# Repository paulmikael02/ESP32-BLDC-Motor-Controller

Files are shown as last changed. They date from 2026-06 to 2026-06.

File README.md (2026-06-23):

# ESP32-Based BLDC Motor Controller (Firmware & Hardware)

***FI** | **[Lue kattava suomenkielinen dokumentaatio tästä](README_FI.md)***

This repository contains the hardware designs (KiCad) and embedded software (ESP-IDF) for a 3-phase brushless DC (BLDC) motor controller.

The project was developed as part of modernizing the educational equipment in the embedded systems laboratory at SeAMK. The old 8-bit ATmega architecture was upgraded to a modern 32-bit ESP32-C6 platform. The new motherboard was designed to directly support the laboratory's legacy analog and digital input/output expansion boards, preserving compatibility with the existing educational environment.

The firmware has been tested with both a small RC car motor and a larger 750W Vevor electric vehicle motor.

## 🚀 Key Features

* **Hardware:** Two-board design separating 3.3V digital logic from high-power electronics.
* **Firmware:** Event-driven C code built using ESP-IDF and FreeRTOS.
* **Motor Control:** 20 kHz hardware PWM with a 1 µs dead-time to protect the MOSFETs.
* **Performance:** Fast, interrupt-driven 6-step commutation optimized in IRAM.

---

## System Architecture

The system consists of two physical printed circuit boards (PCBs) to electrically isolate the sensitive digital logic from the high-current power electronics.

### Architecture Overview
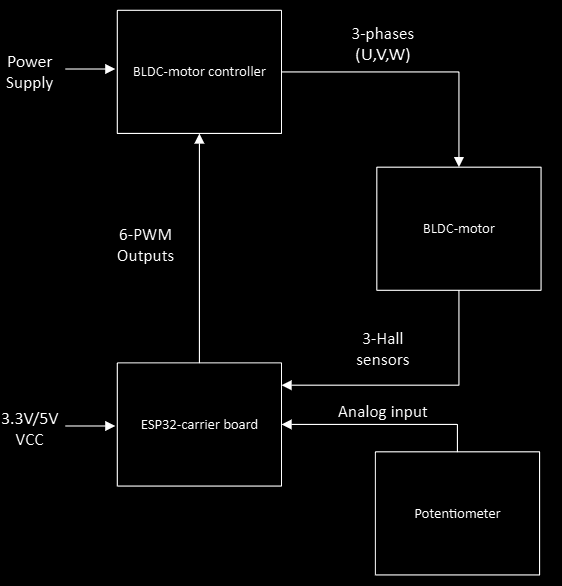
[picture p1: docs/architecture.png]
Technical block diagram of the system architecture


### 1. ESP32 Carrier Board
Contains the ESP32-C6-based microcontroller, decoupling and bulk capacitors, and the necessary filtering for the power supply.
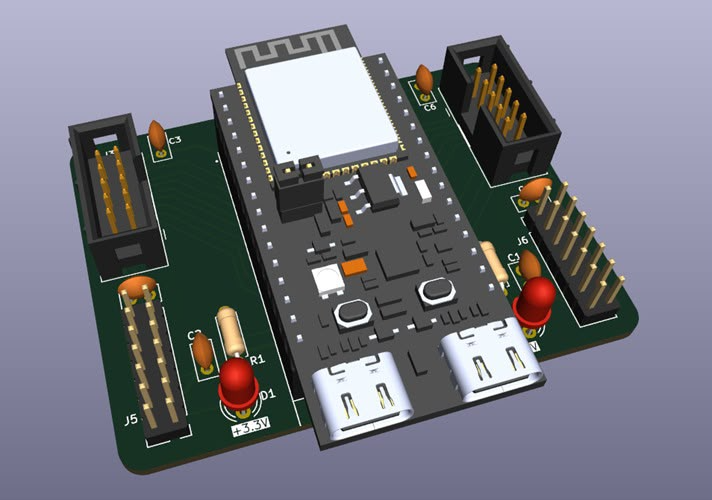
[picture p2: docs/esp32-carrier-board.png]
3D render of the ESP32 Carrier Board


### 2. BLDC Motor Controller
Contains the 3-phase MOSFET inverter bridge, gate drivers, protection diodes, and bulk and decoupling capacitors for the power input.
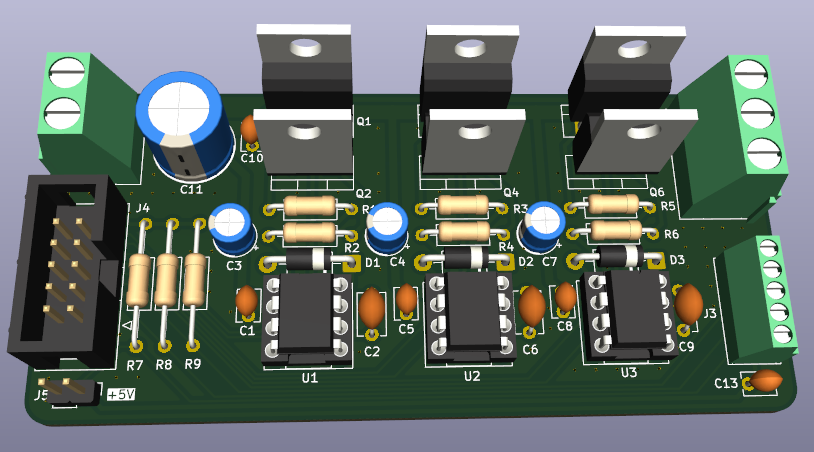
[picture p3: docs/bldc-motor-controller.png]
3D render of the motor controller power stage


---

## 🔌 Pinout Mapping

The physical interface between the software (`include/bldc_control.h`) and the hardware is defined as follows:

| Function | ESP32-C6 Pin | Description / Target on Power Stage |
| :--- | :---: | :--- |
| **PWM U_H / U_L** | GPIO 11 / GPIO 10 | Control for U-phase high- and low-side MOSFETs |
| **PWM V_H / V_L** | GPIO 19 / GPIO 7  | Control for V-phase high- and low-side MOSFETs |
| **PWM W_H / W_L** | GPIO 0 / GPIO 6 | Control for W-phase high- and low-side MOSFETs |
| **Hall U / V / W**| GPIO 5 / GPIO 4 / GPIO 18 | Signal inputs from the motor Hall sensors |
| **Potentiometer** | GPIO 3 (ADC1_CH3)  | Analog voltage input (0–3.3 V) |

---

## 💻 Software Structure and Implementation

The software is written in pure C using the **ESP-IDF (v5.x)** environment and **PlatformIO** tools. The implementation utilizes the FreeRTOS real-time operating system. The software is fully event- and interrupt-driven (no blocking delays), which guarantees accurate motor control even at high rotational speeds.

The code is divided into three logical main components:

### 1. Global Header File and API (`include/bldc_control.h`)
Acts as the hardware definition for the entire system and serves as the public application programming interface (API) for motor control parameters and GPIO definitions. It encapsulates internal helper functions and interrupt handlers away from the main program.

**Low-level critical parameters for motor control:**
* **`PWM_RES_HZ` (10 MHz):** The base clock frequency for the MCPWM module.
* **`PWM_PERIOD` (500):** Defines a 20 kHz PWM frequency ($10\text{ MHz} / 500$). The PWM duty cycle is set between 0 and 500 ticks.
* **`DEAD_TIME_TICKS` (10):** Configures a 1-microsecond hardware dead time between the high- and low-side MOSFETs of each phase to prevent short circuits (shoot-through).
* **GPIO Definitions:** Centralized configurations for the input Hall sensors and power stage transistor outputs.

### 2. Motor Control Logic (`src/bldc_control.c`)
Contains all low-level control logic utilizing the hardware interfaces directly:
* **MCPWM & Dead Time:** Generates the 20 kHz PWM signals for the motor phases and monitors the hardware-level dead time.
* **Interrupt-Driven 6-Step Commutation:** The motor Hall sensors are connected to the MCPWM Capture subsystem. A change in the sensor state triggers an immediate hardware interrupt (`hall_sensor_callback`). To maximize execution speed, the actual commutation function (`update_bldc_commutation`) is placed directly in **IRAM memory**. The code fully supports both forward and reverse commutation sequence tables.
* **FreeRTOS Background Task (`potentiometer_task`):** Handles the potentiometer control and ADC channel processing. It simultaneously calculates the real-time rotational speed from the Hall pulse intervals and filters it using a digital low-pass filter (Exponential Moving Average, $\alpha = 0.10$).

### 3. Main Program (`src/main.c`)
Contains the higher-level application logic. Separate test routines have been built into the file for hardware commissioning:
* **`run_hall_sensor_test()`:** Determines and verifies the sequence and state changes (1–6) of the Hall sensors. The power stage is kept off and the shaft is spun by hand. The order is verified via the serial port, and the motor-specific sequence is updated in the driver's table.
* **`run_speed_ramp_test()`:** Performs an automatic PWM acceleration and braking run to verify the operation of the MOSFET bridges without external interference.
* **Normal Operation (`app_main`):** Runs the main program's `while(1)` loop and tests the code-level direction change sequence (`set_motor_direction`) every 5 seconds.

---

## 📊 Telemetry and Data Visualization

The software outputs real-time data to the serial port every 50 ms. The outputs are formatted using the `>variable:value` standard, allowing direct visualization of the data as a real-time graph using, for example, the **Teleplot** VS Code extension or any Serial Plotter.

**Monitored Variables:**
* `Motor_Duty_Ticks`: PWM pulse width (Counter between 0–500)
* `Hall_State`: Latest state of the Hall sensors (Value between 1–6)
* `Motor_RPM`: Filtered rotational speed (RPM, value is negative when reversing)
* `Motor_Direction`: Direction of rotation (1 = forward, 0 = reverse)

---

## 🛠️ Quick Start

This project is built using **PlatformIO** in VS Code.

```bash
# Clone the repository
git clone https://github.com/paulmikael02/ESP32-BLDC-Motor-Controller.git

# Open in VS Code with the PlatformIO extension installed.
# Build and upload the firmware:
pio run -t upload

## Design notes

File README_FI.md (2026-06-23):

# ESP32-pohjainen BLDC-moottoriohjaus (Firmware & Hardware)

Tämä repositorio sisältää laitteistosuunnitelmat (KiCad) ja sulautetun ohjelmiston (ESP-IDF) 3-vaiheiselle harjattoman tasavirtamoottorin (BLDC) ohjaimelle. 

Projekti on kehitetty osana SeAMK:n sulautettujen järjestelmien laboratorion opetuslaitteiston modernisointia, jossa vanha 8-bittinen ATmega-arkkitehtuuri päivitettiin moderniin 32-bittiseen ESP32-C6-alustaan. Uusi emolevy suunniteltiin tukemaan suoraan laboratorion vanhoja analogisia ja digitaalisia input/output-laajennuskortteja, mikä säilytti olemassa olevan opetusympäristön yhteensopivuuden.

Firmware on testattu sekä pienellä RC-auton moottorilla että suuremmalla 750W Vevor-sähköajoneuvon moottorilla.

---

## Järjestelmäarkkitehtuuri

Järjestelmä koostuu kahdesta fyysisestä piirilevystä, jotta herkkä digitaalilogiikka ja suuriin virtoihin kohdistuva tehoelektroniikka on saatu erotettua sähköisesti toisistaan.

### Yleiskuva arkkitehtuurista
Järjestelmäarkkitehtuurin tekninen lohkokaavio

### 1. ESP32 Carrier board
Sisältää ESP32-C6-pohjaisen mikrokontrollerin, decoupling- ja bulk-kondensaattorit sekä tarvittavan suodatuksen teholähteelle.
ESP32 Carrier Board 3D-renderöinti

### 2. BLDC Motor Controller
Sisältää 3-vaiheisen MOSFET-invertterisillan, hilaohjaimet (Gate Drivers), suojadiodit sekä virransyötön bulk- ja decoupling-kondensaattorit.
Moottoriohjaimen pääteasteen 3D-renderöinti

---

## 🔌 Pinnijärjestys (Pinout Mapping)

Ohjelmiston (`include/bldc_control.h`) ja laitteiston välinen fyysinen liitäntä on määritelty seuraavasti:

| Toiminto | ESP32-C6 Pinni | Kuvaus / Kohde tehoasteella |
| :--- | :---: | :--- |
| **PWM U_H / U_L** | GPIO 11 / GPIO 10 | U-vaiheen ylä- ja alamosfetin ohjaus |
| **PWM V_H / V_L** | GPIO 19 / GPIO 7  | V-vaiheen ylä- ja alamosfetin ohjaus |
| **PWM W_H / W_L** | GPIO 0 / GPIO 6 | W-vaiheen ylä- ja alamosfetin ohjaus |
| **Hall U / V / W**| GPIO 5 / GPIO 4 / GPIO 18 | Moottorin Hall-anturien signaalitulot |
| **Potentiometri** | GPIO 3 (ADC1_CH3)  | Analoginen jännitetulo (0–3.3 V) |

---

## 💻 Ohjelmiston rakenne ja toteutus

Ohjelmisto on kirjoitettu puhtaalla C-kielellä käyttäen **ESP-IDF (v5.x)** -ympäristöä ja **PlatformIO**-työkaluja. Toteutuksessa on hyödynnetty FreeRTOS-reaaliaikakäyttöjärjestelmää. Ohjelmisto on täysin tapahtuma- ja keskeytyspohjainen (ei tukkivia viiveitä), mikä takaa tarkan moottorinohjauksen myös korkeilla pyörintänopeuksilla.

Koodi jakautuu kolmeen loogiseen pääkomponenttiin:

### 1. Globaali otsikkotiedosto ja rajapinta (`include/bldc_control.h`)
Toimii koko järjestelmän laitteistomäärittelynä ja julkisena rajapintana (API) moottoriohjaukseen liittyville parametreille ja GPIO-määritelmille. Se kapseloi sisäiset apufunktiot sekä keskeytyyskäsittelijät piiloon pääohjelmalta.

**Moottorinohjauksen matalan tason kriittiset parametrit:**
* **`PWM_RES_HZ` (10 MHz):** MCPWM-moduulin pohjakellon taajuus.
* **`PWM_PERIOD` (500):** Määrittää 20 kHz PWM-taajuuden ($10\text{ MHz} / 500$). PWM-pulssileveys asetetaan välille 0–500 tickiä.
* **`DEAD_TIME_TICKS` (10):** Asettaa laitteistotasolla 1 mikrosekunnin kuolleen ajan jokaisen vaiheen ylä- ja alamosfetin välille oikosulkujen estämiseksi.
* **GPIO-määritelmät:** Keskitetyt määritykset tulon Hall-antureille ja tehoasteen transistorilähdöille.

### 2. Moottorinohjauslogiikka (`src/bldc_control.c`)
Sisältää kaiken matalan tason ohjauslogiikan suoraan laitteistorajapintoja hyödyntäen:
* **MCPWM & Kuollut aika:** Generoi 20 kHz PWM-signaalit moottorivaiheille ja valvoo laitteistotason kuollutta aikaa.
* **Keskeytyspohjainen 6-vaihekommutaatio:** Moottorin Hall-anturit on kytketty MCPWM Capture -alijärjestelmään. Anturin tilamuutos laukaisee välittömän rautatason keskeytyksen (`hall_sensor_callback`). Nopeuden maksimoimiseksi varsinainen kommutaatiofunktio (`update_bldc_commutation`) on sijoitettu suoraan **IRAM-muistiin**. Koodi tukee täysin eteen- ja taaksepäin suunnattuja kommutaatiotaulukoita.
* **FreeRTOS-taustatehtävä (`potentiometer_task`):** Hoitaa potentiometrin ohjauksen ja ADC-kanavan käsittelyn. Laskee samalla reaaliaikaisen pyörintänopeuden Hall-pulssien aikaväleistä ja suodattaa sen digitaalisella alipäästösuodattimella (Exponential Moving Average, $\alpha = 0.10$).

### 3. Pääohjelma (`src/main.c`)
Sisältää sovelluksen ylemmän tason logiikan. Tiedostoon on rakennettu erilliset testirutiinit laitteiston käyttöönottoa varten:
* **`run_hall_sensor_test()`:** Selvittää ja todentaa Hall-anturien sekvenssin ja tilamuutokset (1–6). Tehoaste pidetään sammuneena ja akselia pyöritetään käsin. Järjestys varmistetaan sarjaportista ja moottorikohtainen sekvenssi päivitetään ajurin taulukkoon.
* **`run_speed_ramp_test()`:** Suorittaa automaattisen PWM-kiihdytys- ja jarrutusajon MOSFET-siltojen toiminnan varmistamiseksi ilman ulkoisia häiriötekijöitä.
* **Normaali ajo (`app_main`):** Pyörittää pääohjelman `while(1)`-silmukkaa ja testaa kooditason suunnanvaihtosekvenssiä (`set_motor_direction`) 5 sekunnin välein.

---

## 📊 Telemetria ja datan visualisointi

Ohjelmisto tulostaa sarjaporttiin reaaliaikaista dataa 50 ms välein. Tulosteet on muotoiltu `>muuttuja:arvo` -standardilla, mikä mahdollistaa datan suoran visualisoinnin reaaliaikaiseksi graafiksi esimerkiksi **Teleplot**-VS Code laajennuksella tai millä tahansa Serial Plotterilla.

**Seurattavat muuttujat:**
* `Motor_Duty_Ticks`: PWM-pulssileveys (Laskuri välillä 0–500)
* `Hall_State`: Viimeisin Hall-anturien tila (Arvo välillä 1–6)
* `Motor_RPM`: Suodatettu pyörintänopeus (RPM, arvo on negatiivinen peruuttaessa)
* `Motor_Direction`: Pyörintäsuunta (1 = eteen, 0 = taakse)

---

## 🚀 Käyttöönotto

1. Avaa tämä projektikansio **VS Code** -ympäristössä, johon on asennettuna **PlatformIO**-laajennus.
2. PlatformIO tunnistaa `platformio.ini`-tiedoston ja lataa tarvittavan ESP-IDF (v5.x) -työkaluketjun automaattisesti taustalla.
3. Käännä koodi ja lataa se kytketylle ESP32-C6-levylle painamalla alareunan nuolikuvaketta tai ajamalla VS Coden terminaalissa komento:
   ```bash
   pio run -t upload

---

## 📸 Testilaitteistot laboratoriossa

![Testaus käynnissä 750W Vevor -sähköajoneuvon moottorilla](docs/750w-vevor.jpg)
![Testaus käynnissä pienellä RC-auton BLDC-moottorilla](docs/rc-motor.jpg)

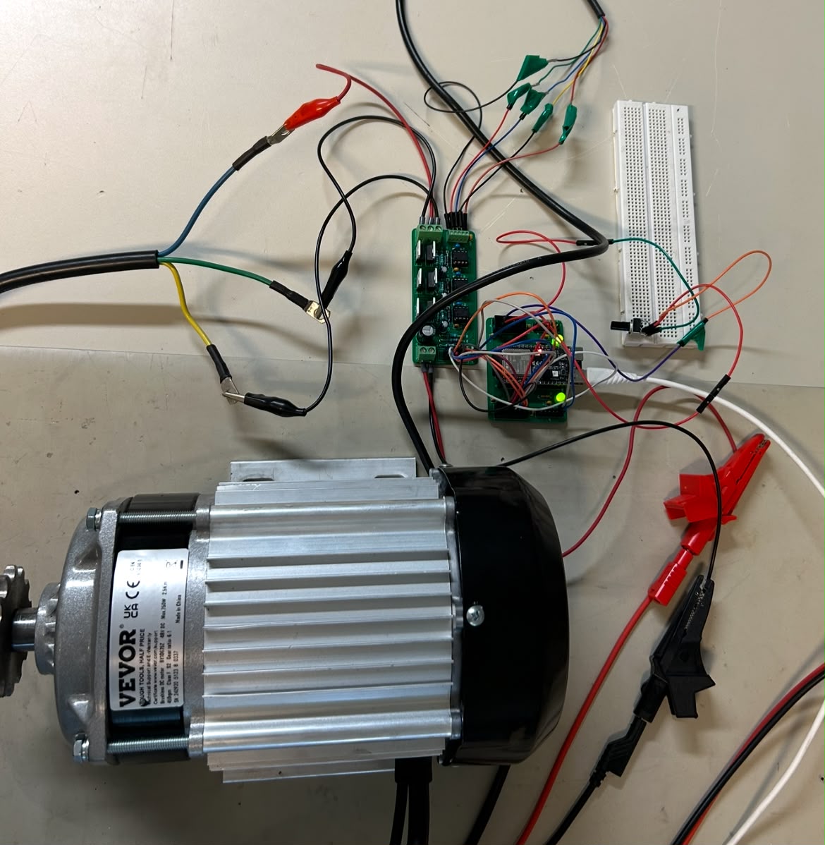
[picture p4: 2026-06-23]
docs/750w-vevor.jpg

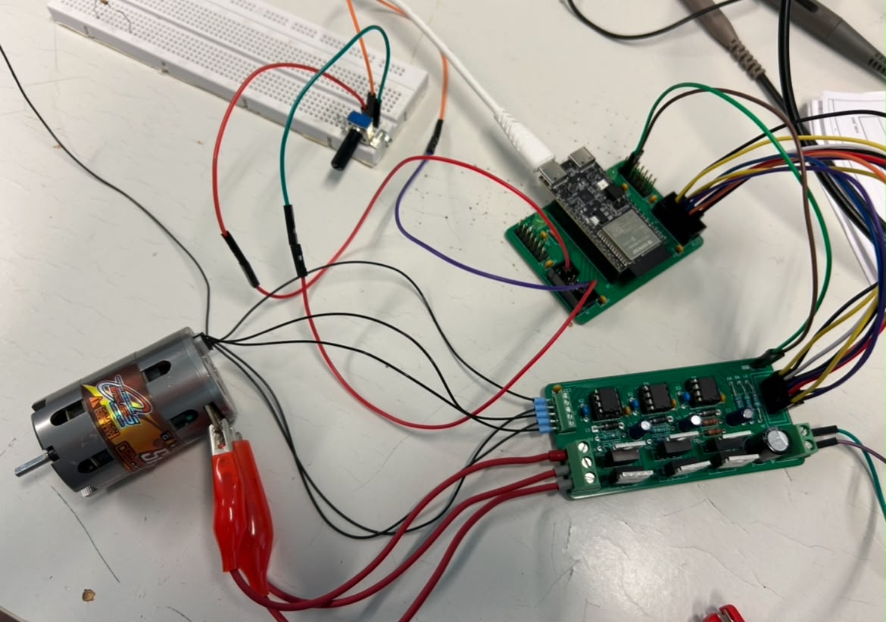
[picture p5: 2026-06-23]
docs/rc-motor.jpg

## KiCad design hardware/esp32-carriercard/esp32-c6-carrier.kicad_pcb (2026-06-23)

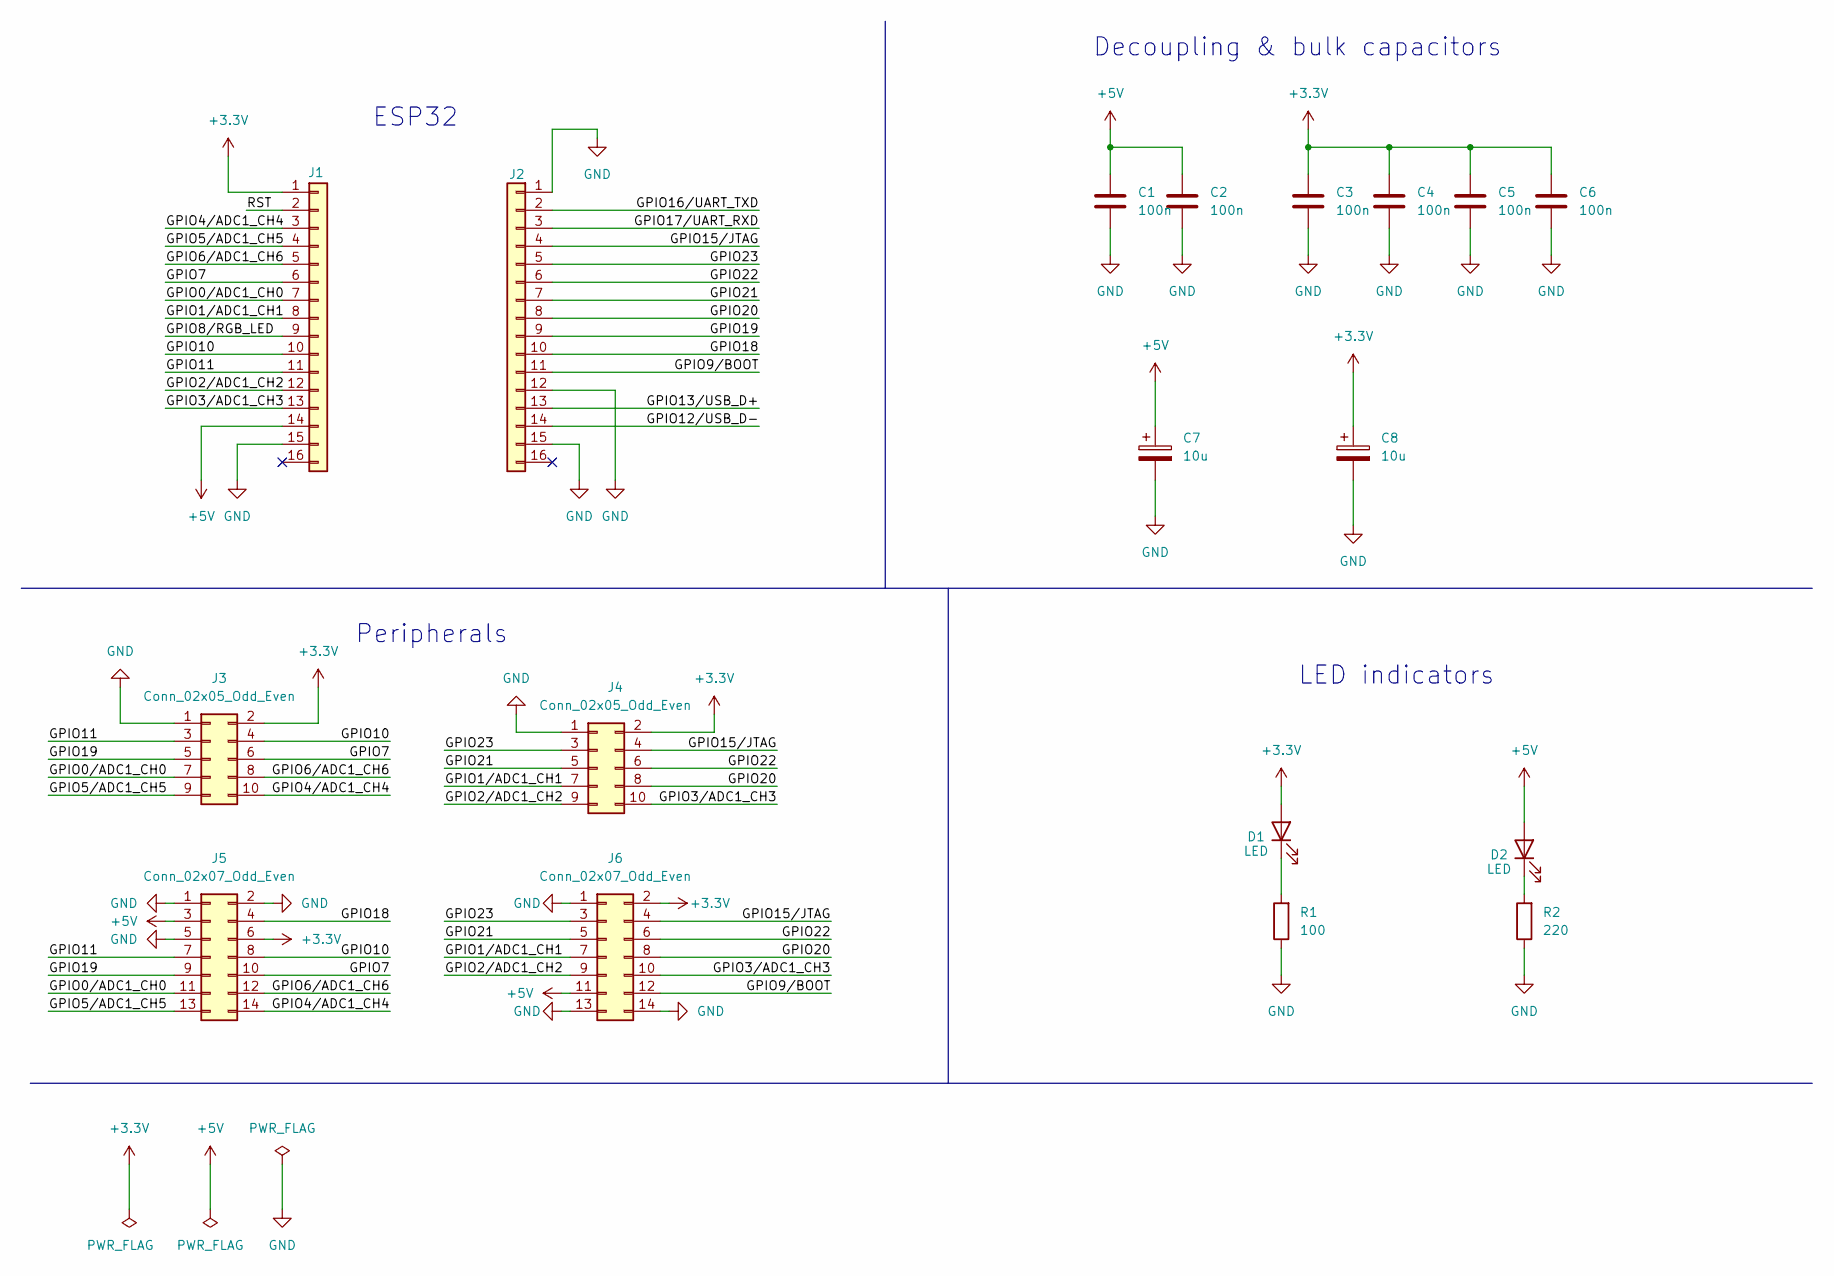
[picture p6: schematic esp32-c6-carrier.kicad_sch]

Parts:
C1, C2, C3, C4, C5, C6: 100n; C_Disc_D3.8mm_W2.6mm_P2.50mm
C7, C8: 10u; CP_Radial_D6.3mm_P2.50mm
D1, D2: LED; LED_D5.0mm
J1, J2: Conn_01x16; PinSocket_1x16_P2.54mm_Vertical
J3, J4: Conn_02x05_Odd_Even; IDC-Header_2x05_P2.54mm_Vertical
J5, J6: Conn_02x07_Odd_Even; PinHeader_2x07_P2.54mm_Vertical
R1: 100; R_Axial_DIN0207_L6.3mm_D2.5mm_P7.62mm_Horizontal
R2: 220; R_Axial_DIN0207_L6.3mm_D2.5mm_P7.62mm_Horizontal

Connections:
+3.3V: C3.1, C4.1, C5.1, C6.1, C8.1, D1.2 (A), J1.1, J3.2, J4.2, J5.6, J6.2
+5V: C1.1, C2.1, C7.1, D2.2 (A), J1.14, J5.3, J6.11
/GPIO0/ADC1_CH0: J1.7, J3.7, J5.11
/GPIO1/ADC1_CH1: J1.8, J4.7, J6.7
/GPIO2/ADC1_CH2: J1.12, J4.9, J6.9
/GPIO3/ADC1_CH3: J1.13, J4.10, J6.10
/GPIO4/ADC1_CH4: J1.3, J3.10, J5.14
/GPIO5/ADC1_CH5: J1.4, J3.9, J5.13
/GPIO6/ADC1_CH6: J1.5, J3.8, J5.12
/GPIO7: J1.6, J3.6, J5.10
/GPIO8/RGB_LED: J1.9
/GPIO9/BOOT: J2.11, J6.12
/GPIO10: J1.10, J3.4, J5.8
/GPIO11: J1.11, J3.3, J5.7
/GPIO12/USB_D-: J2.14
/GPIO13/USB_D+: J2.13
/GPIO15/JTAG: J2.4, J4.4, J6.4
/GPIO16/UART_TXD: J2.2
/GPIO17/UART_RXD: J2.3
/GPIO18: J2.10, J5.4
/GPIO19: J2.9, J3.5, J5.9
/GPIO20: J2.8, J4.8, J6.8
/GPIO21: J2.7, J4.5, J6.5
/GPIO22: J2.6, J4.6, J6.6
/GPIO23: J2.5, J4.3, J6.3
/RST: J1.2
GND: C1.2, C2.2, C3.2, C4.2, C5.2, C6.2, C7.2, C8.2, J1.15, J2.1, J2.12, J2.15, J3.1, J4.1, J5.1, J5.2, J5.5, J6.1, J6.13, J6.14, R1.1, R2.1
unnamed: D1.1 (K), R1.2
unnamed: D2.1 (K), R2.2

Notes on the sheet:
LED indicators
ESP32
Peripherals
Decoupling & bulk capacitors

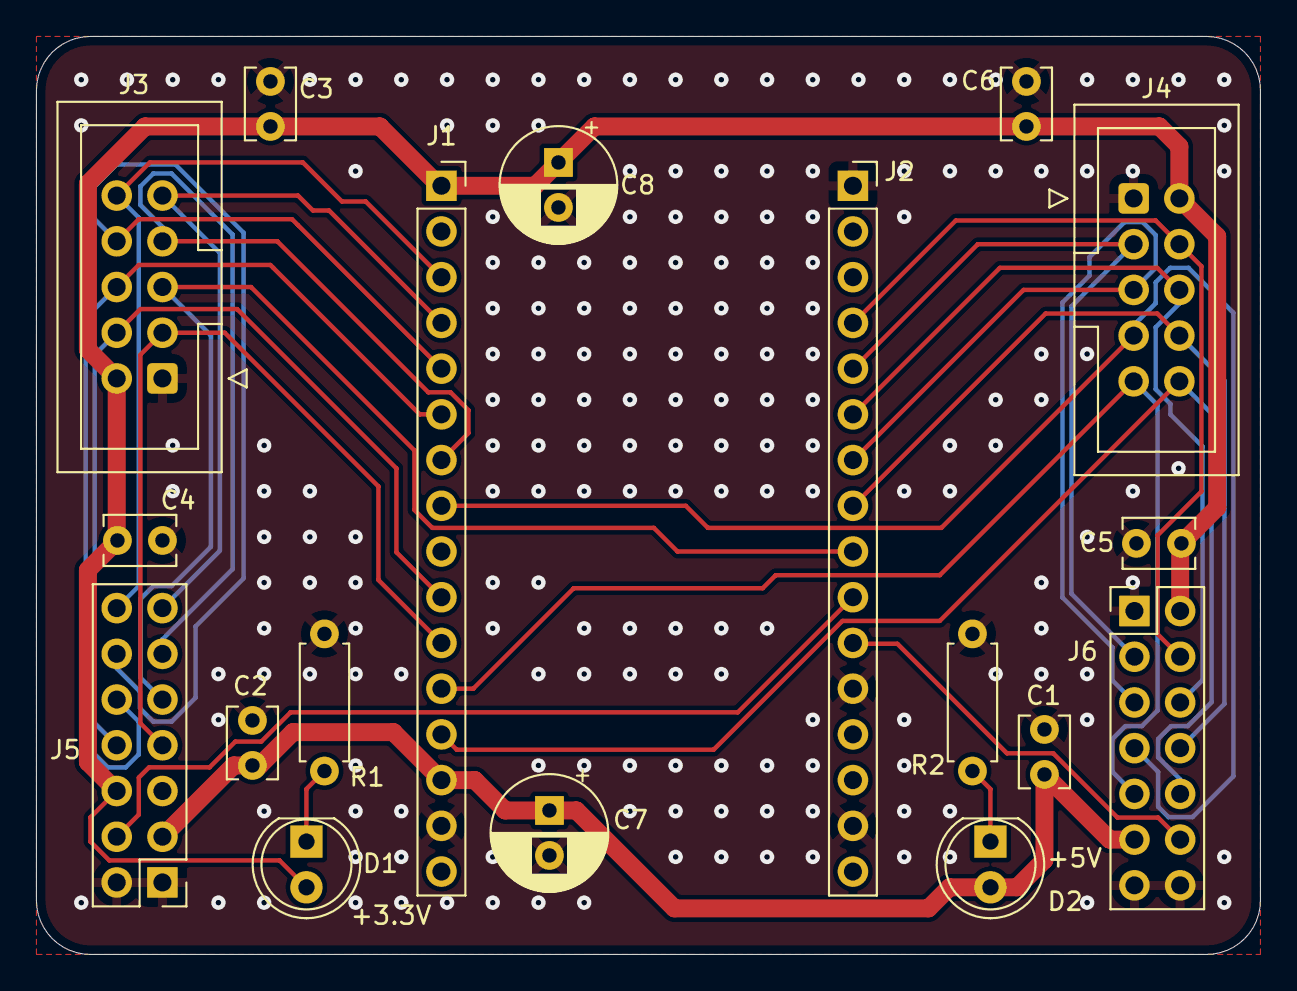
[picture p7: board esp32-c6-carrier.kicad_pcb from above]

Board: 2 copper layers, 68.0 x 51.0 mm, 18 parts (0 on the bottom side), 23 nets.

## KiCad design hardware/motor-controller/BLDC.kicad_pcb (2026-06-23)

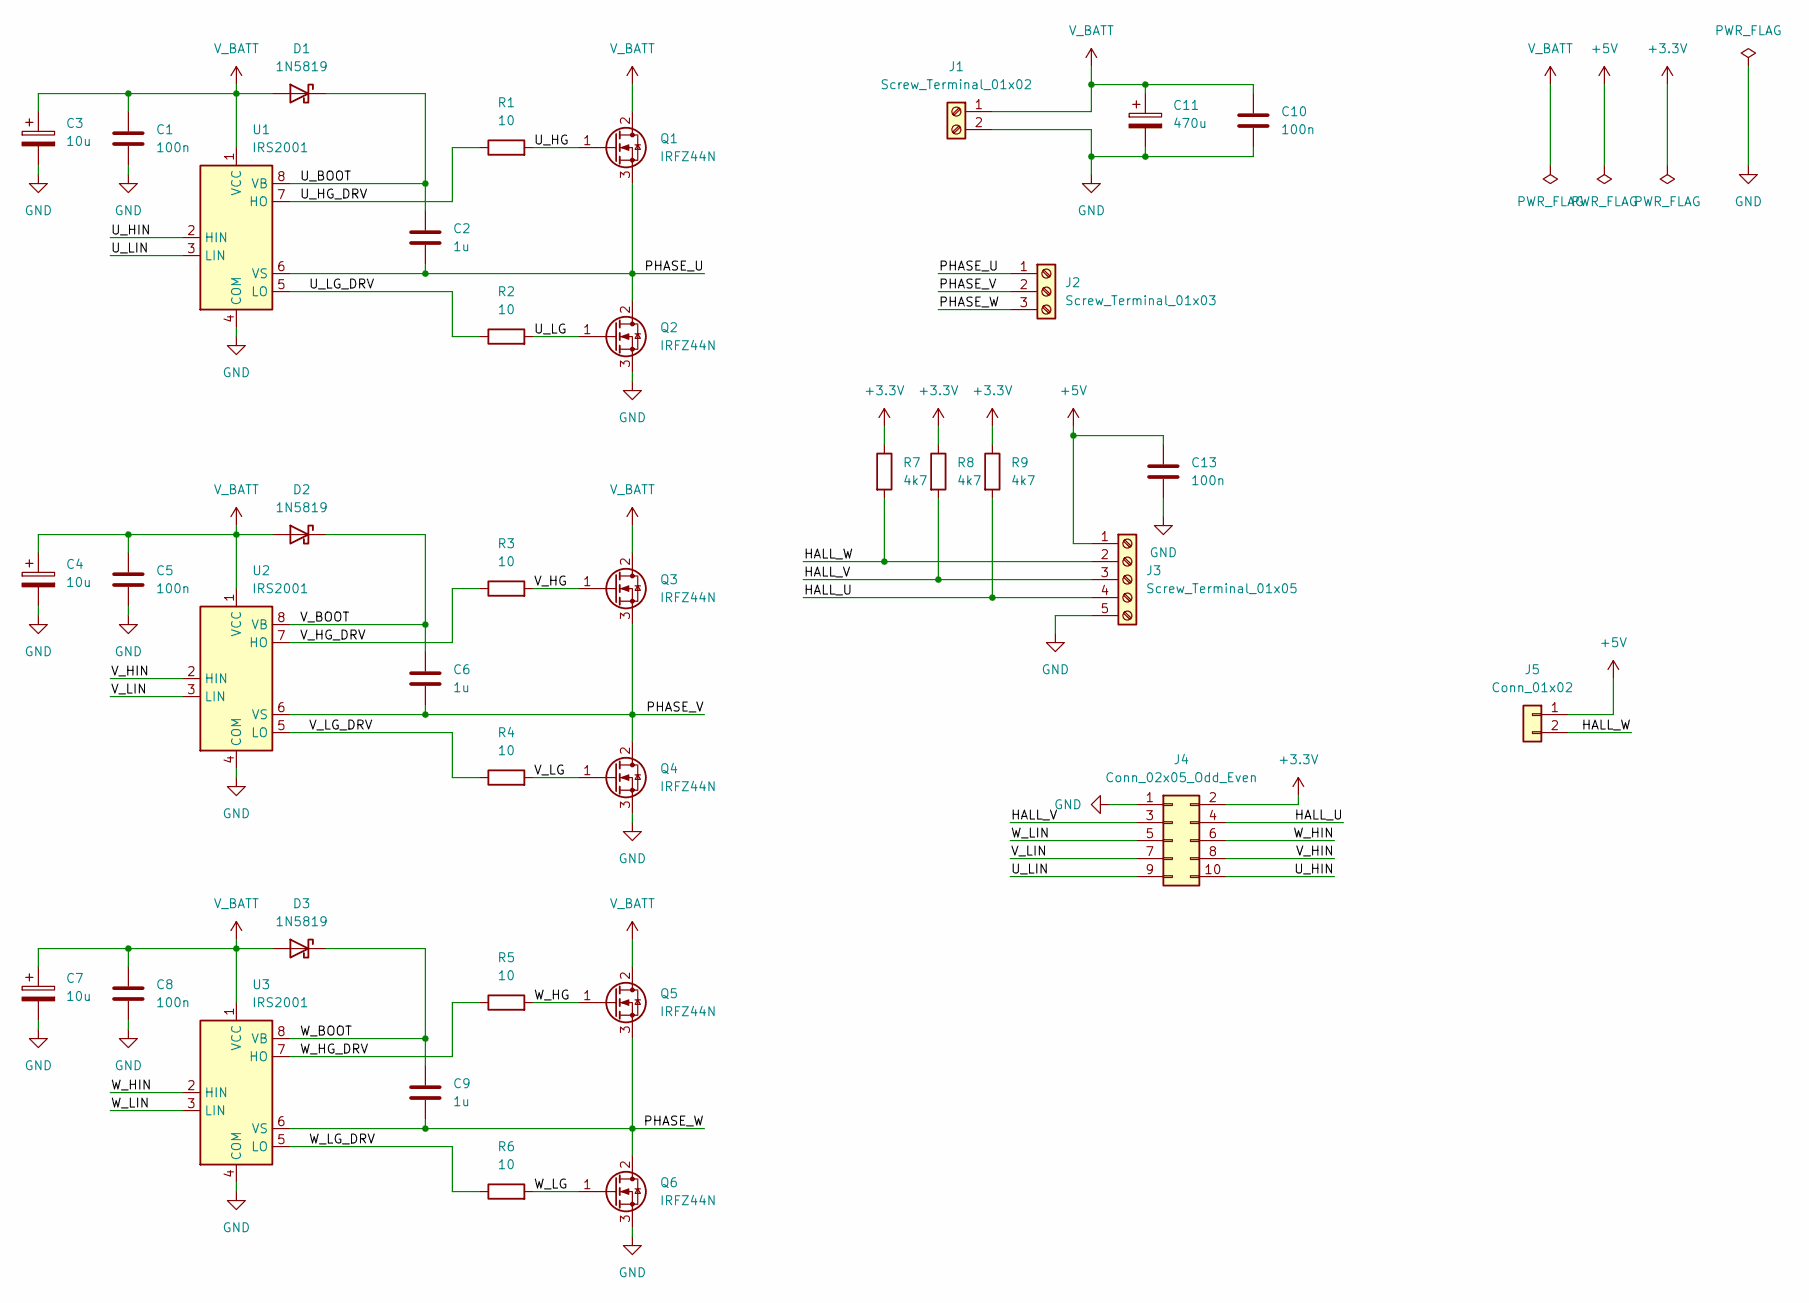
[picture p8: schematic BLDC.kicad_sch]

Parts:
C1, C5, C8, C10, C13: 100n; C_Disc_D3.8mm_W2.6mm_P2.50mm
C2, C6, C9: 1u; C_Disc_D5.1mm_W3.2mm_P5.00mm
C3, C4, C7: 10u; CP_Radial_D5.0mm_P2.00mm
C11: 470u; CP_Radial_D10.0mm_P5.00mm
D1, D2, D3: 1N5819; D_DO-41_SOD81_P10.16mm_Horizontal
J1: Screw_Terminal_01x02; TerminalBlock_Phoenix_MKDS-1,5-2-5.08_1x02_P5.08mm_Horizont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
J2: Screw_Terminal_01x03; TerminalBlock_Phoenix_MKDS-1,5-3-5.08_1x03_P5.08mm_Horizont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
J3: Screw_Terminal_01x05; TerminalBlock_Phoenix_MPT-0,5-5-2.54_1x05_P2.54mm_Horizontal
J4: Conn_02x05_Odd_Even; IDC-Header_2x05_P2.54mm_Vertical
J5: Conn_01x02; PinHeader_1x02_P2.54mm_Vertical
Q1, Q2, Q3, Q4, Q5, Q6: IRFZ44N; TO-220-3_Vertical
R1, R2, R3, R4, R5, R6: 10; R_Axial_DIN0207_L6.3mm_D2.5mm_P10.16mm_Horizontal
R7, R8, R9: 4k7; R_Axial_DIN0207_L6.3mm_D2.5mm_P15.24mm_Horizontal
U1, U2, U3: IRS2001; DIP-8_W7.62mm_Socket

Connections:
+3.3V: J4.2, R7.1, R8.1, R9.1
+5V: C13.1, J3.1, J5.1
/HALL_U: J3.4, J4.4, R9.2
/HALL_V: J3.3, J4.3, R8.2
/HALL_W: J3.2, J5.2, R7.2
/PHASE_U: C2.2, J2.1, Q1.3 (S), Q2.2 (D), U1.6 (VS)
/PHASE_V: C6.2, J2.2, Q3.3 (S), Q4.2 (D), U2.6 (VS)
/PHASE_W: C9.2, J2.3, Q5.3 (S), Q6.2 (D), U3.6 (VS)
/U_BOOT: C2.1, D1.1 (K), U1.8 (VB)
/U_HG: Q1.1 (G), R1.2
/U_HG_DRV: R1.1, U1.7 (HO)
/U_HIN: J4.10, U1.2 (HIN)
/U_LG: Q2.1 (G), R2.2
/U_LG_DRV: R2.1, U1.5 (LO)
/U_LIN: J4.9, U1.3 (LIN)
/V_BOOT: C6.1, D2.1 (K), U2.8 (VB)
/V_HG: Q3.1 (G), R3.2
/V_HG_DRV: R3.1, U2.7 (HO)
/V_HIN: J4.8, U2.2 (HIN)
/V_LG: Q4.1 (G), R4.2
/V_LG_DRV: R4.1, U2.5 (LO)
/V_LIN: J4.7, U2.3 (LIN)
/W_BOOT: C9.1, D3.1 (K), U3.8 (VB)
/W_HG: Q5.1 (G), R5.2
/W_HG_DRV: R5.1, U3.7 (HO)
/W_HIN: J4.6, U3.2 (HIN)
/W_LG: Q6.1 (G), R6.2
/W_LG_DRV: R6.1, U3.5 (LO)
/W_LIN: J4.5, U3.3 (LIN)
GND: C1.2, C3.2, C4.2, C5.2, C7.2, C8.2, C10.2, C11.2, C13.2, J1.2, J3.5, J4.1, Q2.3 (S), Q4.3 (S), Q6.3 (S), U1.4 (COM), U2.4 (COM), U3.4 (COM)
V_BATT: C1.1, C3.1, C4.1, C5.1, C7.1, C8.1, C10.1, C11.1, D1.2 (A), D2.2 (A), D3.2 (A), J1.1, Q1.2 (D), Q3.2 (D), Q5.2 (D), U1.1 (VCC), U2.1 (VCC), U3.1 (VCC)

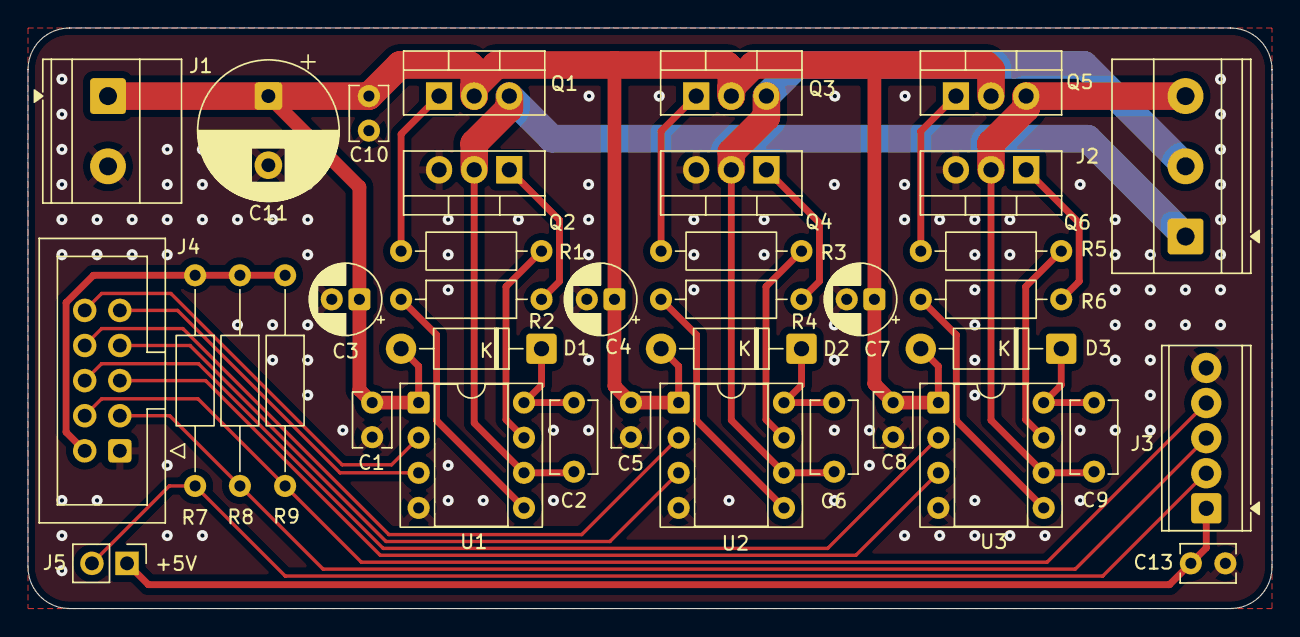
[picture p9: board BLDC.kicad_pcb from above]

Board: 2 copper layers, 90.0 x 42.0 mm, 38 parts (0 on the bottom side), 31 nets.

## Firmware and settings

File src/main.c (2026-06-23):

#include "freertos/FreeRTOS.h"
#include "freertos/task.h"
#include "esp_log.h"
#include "bldc_control.h" 
#include "driver/gpio.h" // Required for the Hall sensor test

static const char *TAG = "MAIN_APP";

// --- STATE MACHINE DEFINITION ---
typedef enum {
    APP_STATE_INIT,
    APP_STATE_RUN_FORWARD,
    APP_STATE_RUN_REVERSE
} app_state_t;

// --- TEST FUNCTIONS ---

void run_speed_ramp_test(void) {
    ESP_LOGI("TEST", "Starting Speed Ramp Test (0 to 250 ticks)..."); // 0-500 (max) PWM ticks
    init_bldc_pwm();
    init_hall_sensors();
    bldc_force_initial_commutation();

    while (1) {
        for (uint32_t speed = 0; speed <= 250; speed += 10) {
            set_motor_speed(speed);
            vTaskDelay(pdMS_TO_TICKS(100)); 
        }
        vTaskDelay(pdMS_TO_TICKS(1000)); 
        for (uint32_t speed = 250; speed > 0; speed -= 10) {
            set_motor_speed(speed);
            vTaskDelay(pdMS_TO_TICKS(100));
        }
        set_motor_speed(0);
        vTaskDelay(pdMS_TO_TICKS(2000)); 
    }
}

void run_hall_sensor_test(void) {
    ESP_LOGI("TEST", "Hall Sensor Monitor Active. Spin the motor shaft manually!");
    init_hall_sensors();
    
    while (1) {
        uint32_t hall_val = (gpio_get_level(PIN_HALL_U) << 2) | 
                            (gpio_get_level(PIN_HALL_V) << 1) | 
                            (gpio_get_level(PIN_HALL_W));
        printf("Current Hall State: %lu\n", hall_val);
        vTaskDelay(pdMS_TO_TICKS(500));
    }
}

// --- MAIN PROGRAM ---

void app_main(void) {
    // ---------------------------------------------------------
    // TEST MODE: Uncomment the test you want to run. 
    // Ensure that the normal operation block below is commented out.
    // ---------------------------------------------------------
    
    // run_hall_sensor_test();
    // run_speed_ramp_test();

    // ---------------------------------------------------------
    // NORMAL OPERATION: Non-blocking state machine
    // ---------------------------------------------------------
    app_state_t current_state = APP_STATE_INIT;
    TickType_t state_start_time = 0; // For FreeRTOS time tracking

    while (1) {
        switch (current_state) {
            
            case APP_STATE_INIT:
                ESP_LOGI(TAG, "Initializing BLDC Controller...");
                init_bldc_pwm();
                init_hall_sensors();
                init_potentiometer_adc();
                bldc_force_initial_commutation();
                bldc_start_control_task();
                
                ESP_LOGI(TAG, "Starting forward operation...");
                set_motor_direction(1);
                state_start_time = xTaskGetTickCount(); // Start the stopwatch
                current_state = APP_STATE_RUN_FORWARD;
                break;

            case APP_STATE_RUN_FORWARD:
                // Check if 5 seconds (5000 ms) have elapsed
                if ((xTaskGetTickCount() - state_start_time) >= pdMS_TO_TICKS(5000)) {
                    ESP_LOGI(TAG, "5s elapsed, changing direction to REVERSE.");
                    set_motor_direction(0);
                    state_start_time = xTaskGetTickCount(); // Reset the timer
                    current_state = APP_STATE_RUN_REVERSE;
                }
                break;

            case APP_STATE_RUN_REVERSE:
                // Check if 5 seconds (5000 ms) have elapsed
                if ((xTaskGetTickCount() - state_start_time) >= pdMS_TO_TICKS(5000)) {
                    ESP_LOGI(TAG, "5s elapsed, changing direction to FORWARD.");
                    set_motor_direction(1);
                    state_start_time = xTaskGetTickCount(); // Reset the timer
                    current_state = APP_STATE_RUN_FORWARD;
                }
                break;
        }

        // A small 10ms delay prevents the loop from consuming 100% CPU 
        // and gives breathing room for RTOS background tasks.
        vTaskDelay(pdMS_TO_TICKS(10));
    }
}

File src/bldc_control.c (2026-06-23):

#include "bldc_control.h"
#include <stdio.h>
#include "freertos/FreeRTOS.h"
#include "freertos/task.h"
#include "driver/gpio.h"
#include "driver/mcpwm_prelude.h"
#include "esp_log.h"
#include "esp_attr.h"
#include "esp_adc/adc_oneshot.h"
#include "esp_adc/adc_cali.h"        
#include "esp_adc/adc_cali_scheme.h" 
#include "esp_timer.h"

static const char *TAG = "BLDC_HW";

// --- PRIVATE GLOBAL HANDLES (Encapsulated inside this file) ---
static mcpwm_timer_handle_t timer = NULL;
static mcpwm_oper_handle_t oper_u = NULL, oper_v = NULL, oper_w = NULL;
static mcpwm_cmpr_handle_t cmpr_u = NULL, cmpr_v = NULL, cmpr_w = NULL;
static mcpwm_gen_handle_t gen_u_h = NULL, gen_u_l = NULL;
static mcpwm_gen_handle_t gen_v_h = NULL, gen_v_l = NULL;
static mcpwm_gen_handle_t gen_w_h = NULL, gen_w_l = NULL;
static adc_oneshot_unit_handle_t adc1_handle = NULL; 
static adc_cali_handle_t cali_handle = NULL;
static volatile uint64_t bldc_last_hall_time = 0;
static volatile uint32_t bldc_rev_period_us = 0;

volatile uint32_t current_duty = 0;
volatile uint32_t latest_hall_val = 0; // Stores the latest Hall state safely for telemetry

// Direction control: 1 = Forward, 0 = Reverse
volatile uint8_t motor_direction = 1;
volatile uint8_t motor_direction_changing = 0;

// --- PRIVATE HARDWARE COMMUTATION LOGIC ---
// Placed in IRAM for maximum execution speed inside the interrupt context
static inline void IRAM_ATTR update_bldc_commutation(uint32_t hall_val) {
    // Forward sequence verified with the Vevor BLDC motor
    const uint8_t seq_forward[6] = {4, 6, 2, 3, 1, 5};
    // Reverse sequence: exactly inverted order
    const uint8_t seq_reverse[6] = {3, 4, 5, 2, 6, 1};

    const uint8_t *seq = (motor_direction == 1) ? seq_forward : seq_reverse;

    int index = -1;
    for (int i = 0; i < 6; i++) {
        if (seq[i] == hall_val) {
            index = i;
            break;
        }
    }

    if (index != -1) {
        int shifted_index = (index + 1) % 6; // Always advance +1 within the selected sequence table
        hall_val = seq[shifted_index];
    }

    // Apply the 6-step commutation states to the MCPWM generators
    switch(hall_val) {
        case 5: 
            mcpwm_generator_set_force_level(gen_u_h, 0, true);  mcpwm_generator_set_force_level(gen_u_l, 1, true);
            mcpwm_generator_set_force_level(gen_v_h, 0, true);  mcpwm_generator_set_force_level(gen_v_l, 0, true);
            mcpwm_generator_set_force_level(gen_w_h, -1, true); mcpwm_generator_set_force_level(gen_w_l, -1, true);
            break;
        case 1: 
            mcpwm_generator_set_force_level(gen_u_h, 0, true);  mcpwm_generator_set_force_level(gen_u_l, 0, true);
            mcpwm_generator_set_force_level(gen_v_h, 0, true);  mcpwm_generator_set_force_level(gen_v_l, 1, true);
            mcpwm_generator_set_force_level(gen_w_h, -1, true); mcpwm_generator_set_force_level(gen_w_l, -1, true);
            break;
        case 3: 
            mcpwm_generator_set_force_level(gen_u_h, -1, true); mcpwm_generator_set_force_level(gen_u_l, -1, true);
            mcpwm_generator_set_force_level(gen_v_h, 0, true);  mcpwm_generator_set_force_level(gen_v_l, 1, true);
            mcpwm_generator_set_force_level(gen_w_h, 0, true);  mcpwm_generator_set_force_level(gen_w_l, 0, true);
            break;
        case 2: 
            mcpwm_generator_set_force_level(gen_u_h, -1, true); mcpwm_generator_set_force_level(gen_u_l, -1, true);
            mcpwm_generator_set_force_level(gen_v_h, 0, true);  mcpwm_generator_set_force_level(gen_v_l, 0, true);
            mcpwm_generator_set_force_level(gen_w_h, 0, true);  mcpwm_generator_set_force_level(gen_w_l, 1, true);
            break;
        case 6: 
            mcpwm_generator_set_force_level(gen_u_h, 0, true);  mcpwm_generator_set_force_level(gen_u_l, 0, true);
            mcpwm_generator_set_force_level(gen_v_h, -1, true); mcpwm_generator_set_force_level(gen_v_l, -1, true);
            mcpwm_generator_set_force_level(gen_w_h, 0, true);  mcpwm_generator_set_force_level(gen_w_l, 1, true);
            break;
        case 4: 
            mcpwm_generator_set_force_level(gen_u_h, 0, true);  mcpwm_generator_set_force_level(gen_u_l, 1, true);
            mcpwm_generator_set_force_level(gen_v_h, -1, true); mcpwm_generator_set_force_level(gen_v_l, -1, true);
            mcpwm_generator_set_force_level(gen_w_h, 0, true);  mcpwm_generator_set_force_level(gen_w_l, 0, true);
            break;
        default:
            // Safe default state: shut down all phases to prevent short circuits
            mcpwm_generator_set_force_level(gen_u_h, 0, true); mcpwm_generator_set_force_level(gen_u_l, 0, true);
            mcpwm_generator_set_force_level(gen_v_h, 0, true); mcpwm_generator_set_force_level(gen_v_l, 0, true);
            mcpwm_generator_set_force_level(gen_w_h, 0, true); mcpwm_generator_set_force_level(gen_w_l, 0, true);
            break;
    }
}

// --- PRIVATE HALL SENSOR INTERRUPT CALLBACK ---
static bool IRAM_ATTR hall_sensor_callback(mcpwm_cap_channel_handle_t cap_channel, const mcpwm_capture_event_data_t *edata, void *user_ctx) {
    // Read current Hall sensor states and build a 3-bit value (U = MSB, W = LSB)
    uint32_t hall_val = (gpio_get_level(PIN_HALL_U) << 2) |
                        (gpio_get_level(PIN_HALL_V) << 1) |
                        (gpio_get_level(PIN_HALL_W));
    latest_hall_val = hall_val;
    update_bldc_commutation(hall_val);

    // Measure time period between consecutive U phase pulses for RPM tracking
    // Checks if it is the Hall U channel (context == 1) and a positive rising edge
    if ((int)user_ctx == 1 && edata->cap_edge == MCPWM_CAP_EDGE_POS) {
        uint64_t now = esp_timer_get_time();
        bldc_rev_period_us = now - bldc_last_hall_time;
        bldc_last_hall_time = now;
    }

    return false; // Return false as we do not need a FreeRTOS task yield here
}
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

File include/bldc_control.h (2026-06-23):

#ifndef BLDC_CONTROL_H
#define BLDC_CONTROL_H

#include <stdint.h>

// --- PIN CONFIGURATIONS ---
#define PIN_U_H 11
#define PIN_U_L 10
#define PIN_V_H 19
#define PIN_V_L 7
#define PIN_W_H 0
#define PIN_W_L 6
 
#define PIN_HALL_U 5
#define PIN_HALL_V 4
#define PIN_HALL_W 18

#define PIN_POTENTIOMETER 3
#define ADC_POT_CHANNEL ADC_CHANNEL_3

// --- SYSTEM PARAMETERS ---
#define PWM_RES_HZ 10000000 // 10 MHz clock for MCPWM module
#define PWM_PERIOD 500      // 20 kHz PWM frequency (10MHz / 500)
#define DEAD_TIME_TICKS 10  // 1 microsecond deadtime delay



// --- PUBLIC FUNCTION DECLARATIONS ---
void init_bldc_pwm(void);
void init_hall_sensors(void);
void init_potentiometer_adc(void);
void bldc_force_initial_commutation(void);
void bldc_start_control_task(void);
void set_motor_speed(uint32_t duty_ticks);
void set_motor_direction(uint8_t direction);

#endif // BLDC_CONTROL_H
